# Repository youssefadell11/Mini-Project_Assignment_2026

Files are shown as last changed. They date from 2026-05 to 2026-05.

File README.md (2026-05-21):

# Cooling and Sorting Automated Chocolate Bars Production Line 🍫🤖

## Project Overview
This repository contains the mechanical design, electrical schematics, mathematical models, and simulation files for an automated mechatronic production line. The system is engineered to seamlessly convey, cool, weigh, and sort chocolate bars in a high-throughput food processing environment.

## Key Features
* **Closed-Loop Thermal Management:** Dynamic forced-air cooling modulated by a PID controller responding to real-time non-contact IR temperature feedback ($20^\circ$C target).
* **Adaptive Conveyor Speed:** Variable speed regulation (nominal $0.1 \text{ m/s}$) to ensure sufficient cooling residence time.
* **Automated Sorting Mechanism:** A 3-axis Cartesian robotic arm and pneumatic diversion system for high-speed rejection of out-of-spec products (overheated, under-cooled, or improper weight).
* **Dual-Controller Architecture:** Distributed computing utilizing ESP-based microcontrollers for parallel processing of motor control (PWM) and sensor arrays (HX711 Load Cell, MLX90614 IR).

## Repository Contents
* `/1_CAD`: 3D assembly and part files for the conveyor, rotary feeder, and Cartesian robotic sorter.
<p align="center">
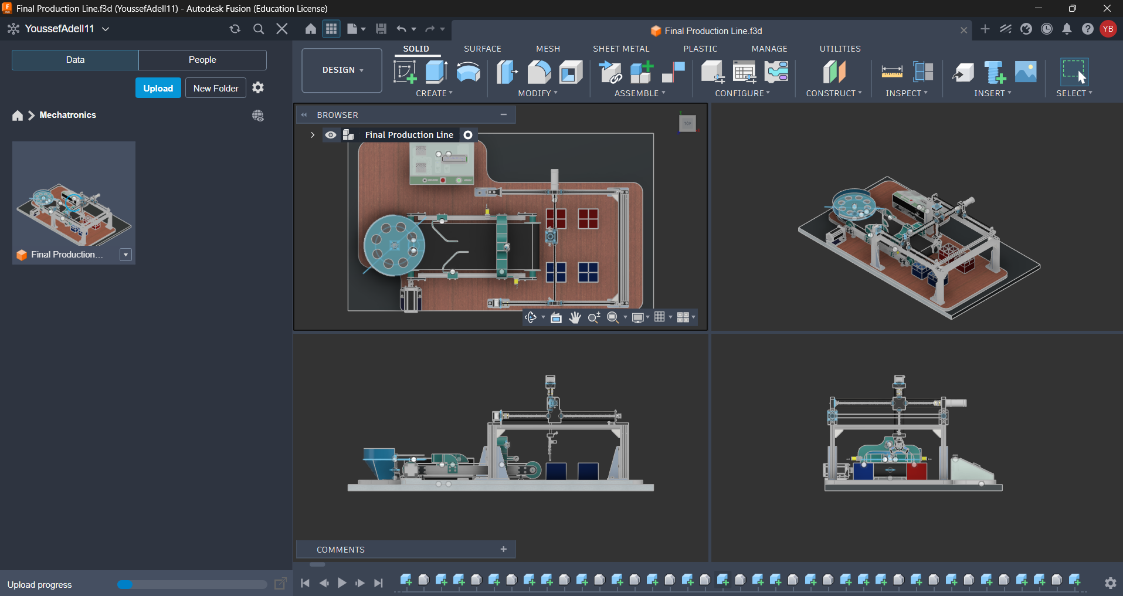
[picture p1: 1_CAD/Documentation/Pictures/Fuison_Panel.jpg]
Fusion Panel
  
</p>

* `/2_Simulation`: MATLAB Simscape physical network models and Simulink block diagrams for the PID control and thermal dynamics.
<p align="center">
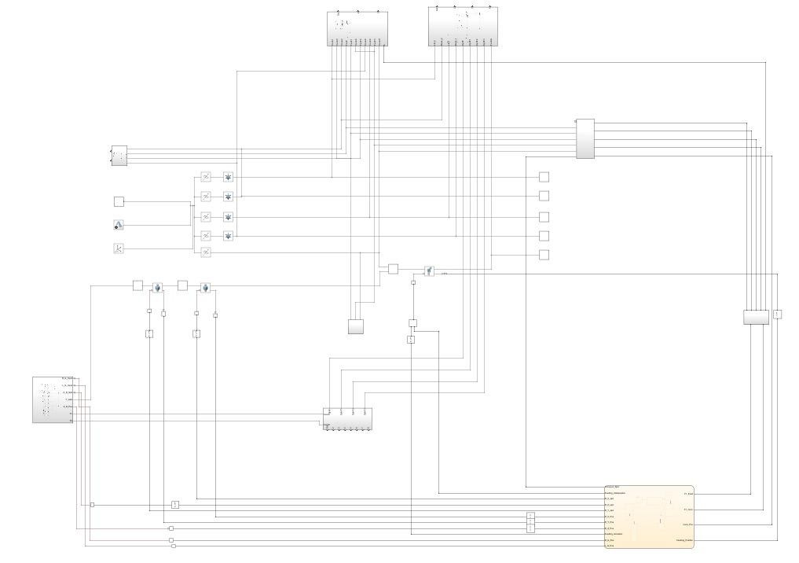
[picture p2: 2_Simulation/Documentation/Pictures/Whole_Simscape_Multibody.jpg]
Simscape Multibody
  
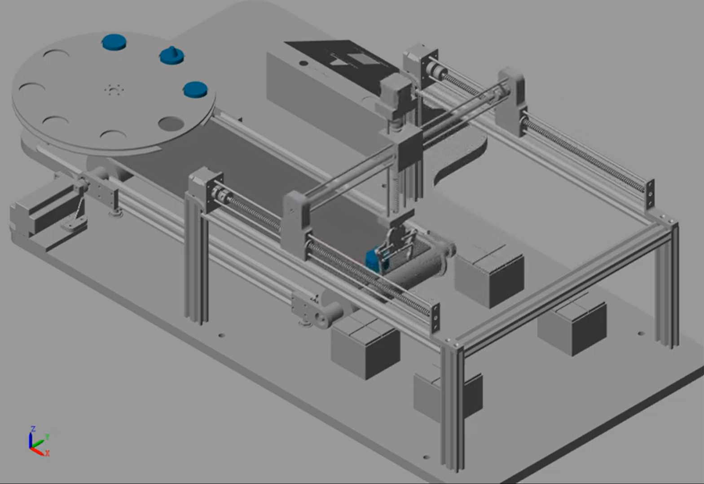
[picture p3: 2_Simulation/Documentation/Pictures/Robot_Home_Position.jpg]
Robot Home Position
  
</p>

* `/3_Documentation`: The final compiled LaTeX technical report and force analysis derivations.

## Technologies Used
* **Simulation & Control:** MATLAB, Simulink, Simscape
* **Computing:** ESP32/Arduino, C++
* **CAD Design:** Autodesk Fusion 360

## Demonstration & Files

* 🎥 **YouTube Video:** [CAD Design: Automated Cooling and Sorting Chocolate Production Line](https://youtu.be/Yx4FxSzs9Yo)
* 📊 **YouTube Video:** [MATLAB Simulation: Automated Cooling and Sorting Chocolate Production Line](https://youtu.be/9laI-daexsU)
* 🛠️ **Interactive Model:** [View the 3D CAD Assembly on Autodesk Fusion 360](https://a360.co/4fo8kH5)

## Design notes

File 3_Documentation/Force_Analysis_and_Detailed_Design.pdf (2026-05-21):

## 1 Actuator Sizing

### 1.1 Actuator Sizing for Gripper

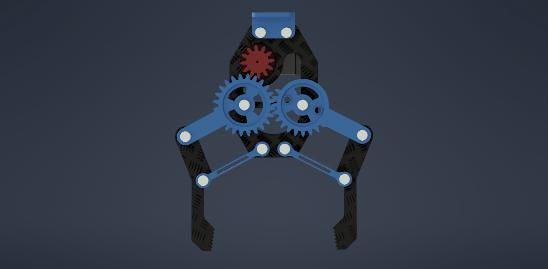
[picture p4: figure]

Figure 1: Gripper Mechanism

1- Normal Force Move Up:

Fup ≥

m(g + a)
2u

Fup =

m(g + a)
2u

× S.f

The required force (F) is calculated as:

Fup =

0.04 × (9.8 + .4)
2 × 0.4

× 2

Fup = 1.02 N

Calculation of Torque:
T = F × d

Tup = 1.02 × .1 = 0.102 N.m

2- Force Move Sideways:

Freq =

p
fx² + fy²

Freq =

p
(ma)

2 + (mg)

2

The required force (F) is calculated as:

Fside =

p
(ma)

2 + (mg)

2
2u

× S.f

Fside =

p
(.04 × .4)² + (9.8 × .04)² 2 × .4

× 2

Fside = .98 N

Calculation of Torque:
T = F × d

Tside = .98 × .1 = 0.098 N.m

Symbol | Value | Units
us | 0.4
g | 9.8 | m/s²
S.f | 2
m | 0.04 | kg
a | 0.4 | m/s²
d | 0.1 | m

3- Force Move down:

Fdown ≥

m(g − a)
2u

Fdown =

m(g − a)
2u

× S.f

The required force (F) is calculated as:

Fdown =

0.04 × (9.8 − .4)
2 × 0.4

× 2

Fdown = .94 N

Calculation of Torque:
T = F × d

Tdown = .94 × .1 = 0.094 N.m

4- Validation: From analysis, the gripper mechanism requires a peak torque = 0.102 N-m.
The selected MG996R Servo Motor has a maximum torque of 1.1 N-m (in its datasheet).
Since this value is significantly higher than the required peak torque = 0.102 N-m, the motor provides a large safety margin and ensures stable and reliable gripping performance.

### 1.2 Actuator Sizing for Z-Axis

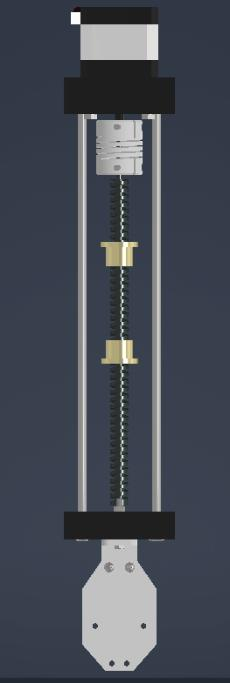
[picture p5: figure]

Figure 2: Z-Axis Mechanism

Symbol | Value Used | Units (SI)
mL | 1.118 | kg
η | 0.40
ρ | 7800 | kg/m³
D | 8 | mm
L | 0.400 | m
P | 0.125 | rev/mm
g | 9.81 | m/s²
tacc | 0.160 | s
tc | 0.500 | s
tdec | 0.160 | s
θacc | 392.70 | rad/s²
Θ′
max | 62.83 | rad/s
Ninertia | 1 | JL,total/Jm
S.f | 1.5

1- Inertia Calculations
Effective Load Inertia:
| JL = mL
| η[2πp]

2

| JL =
| 1.118
.40[2π × 125]²

JL = 4.5302 × 10⁻⁶
| | kg.m²

Lead Screw Inertia:
| Jscrew = π
| 2

ρLr⁴

Jscrew =

π
2

× 7800 × .4 × .004⁴

Jscrew = 1.2546 × 10⁻⁶
kg.m²

Total Load Inertia:
JLt = Jscrew + JL = 5.7848 × 10⁻⁶ kg.m²

Equivalent Inertia:
JLt = Jm

Jeq = JLt + Jm = 2JLt
Jeq = 1.1570 × 10⁻⁵
kg.m²

2- Load Torque Calculation Load Force:
fL = ML × g

fL = 1.118 × 9.8 = 10.9694 N

Load Torque:

TL =

FL
2πp × η

TL = 0.0349 N.m

3- Motion Profile
Assume a motion profile where: Θ′

max = 62.83 rad.s⁻¹
, tacc = 0.160 s, tc = 0.500 s, tdec = 0.160 s, tdwell = 0.

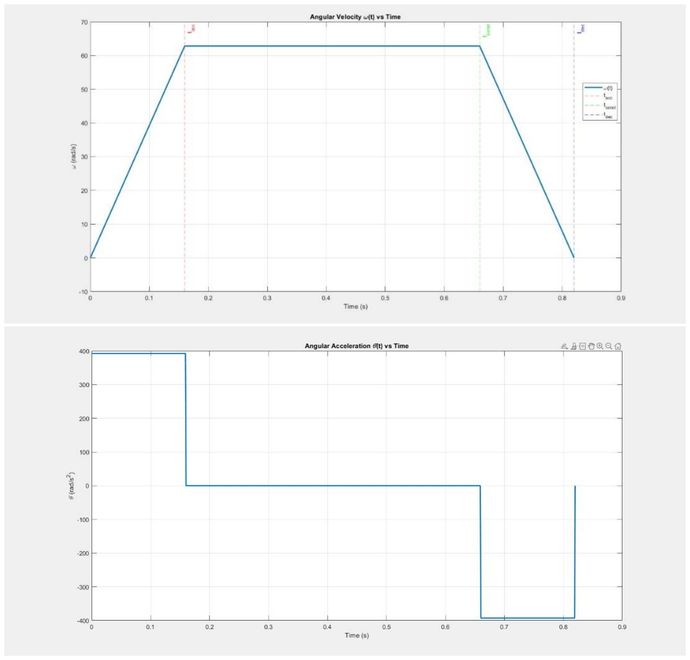
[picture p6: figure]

Figure 3: Angular Velocity and Acceleration vs Time

Now calculate the angular acceleration:

θacc = 392.70 rad.s⁻²

θconst = 0
θdec = −392.70 rad.s⁻²

4- Peak and RMS Torque Calculations Acceleration Torque:
Tm = Jeq

¨θ + TL

Tmacc = (1.1570 × 10⁻⁵ × 392.7) + 0.0349

Tmacc = 0.0395 N.m

Tpeak = Tmacc × S.f = 0.05925 N.m

Constant Velocity Torque:
Tmc = TL = 0.0349 N.m

Deceleration Torque:
Tmdec = (1.1570 × 10⁻⁵ × −392.7) + 0.0349

Tmdec = 0.0304 N.m

Peak Torque (RMS):

Trms =

s
Tmacc

2 × tacc + Tmc

2 × tc + Tmdec

2 × tdec

tacc + tc + tdec

× S.f

Trms =

r
0.0395² × 0.16 + 0.0349² × 0.5 + 0.0304² × 0.16 .820

× 1.5

Trms = 0.05265 N.m

5- Validation Based on the analysis, the Z-axis linear motion requires a peak torque = 0.05925 N-m and an RMS torque = 0.05265 N-m. The selected NEMA 17 Stepper Motor has a maximum torque = 0.59 N-m. Since this value is much higher, the motor provides a large safety margin.

### 1.3 Actuator Sizing for Y-Axis

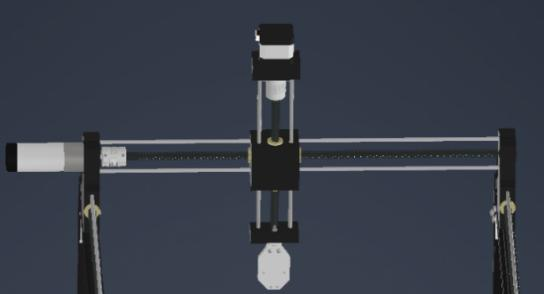
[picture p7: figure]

Figure 4: Y-Axis Mechanism

Symbol | Value | Units
η | 0.40
P | 0.125 | rev/mm
D | 8.0 | mm
mL | 1.320 | kg
Lscrew | 600 | mm
S.f | 1.5
g | 9.81 | m/s²
tacc | 0.1600 | s
tc | 4.8400 | s
tdec | 0.1600 | s
Θ′
max | 62.8319 | rad/s
θacc | 392.6991 | rad/s²
Ninertia | 1.0

1- Inertia Calculations
Effective Load Inertia:
JL =

1.320
.40[2π × 125]²

= 5.349 × 10⁻⁶
kg.m²

Lead Screw Inertia:

Jscrew =

π
2

× 7800 × .6 × .004⁴ = 1.882 × 10⁻⁶ kg.m²

Total Load Inertia:
JLt = Jscrew + JL = 7.2304 × 10⁻⁶ kg.m²

Equivalent Inertia:
Jeq = 2JLt = 1.4461 × 10⁻⁵ kg.m²

2- Load Torque Calculation Load Force:
fL = 1.320 × 9.8 = 12.936 N

Load Torque:

TL =

FL
2πp × η

= 0.0412 N.m

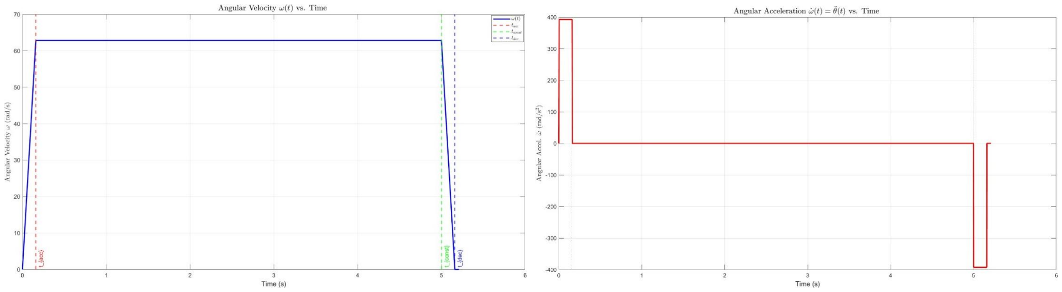
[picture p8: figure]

Figure 5: Angular Velocity and Acceleration vs Time (Y-Axis)

4- Peak and RMS Torque Calculations

Tmacc = (1.4461 × 10⁻⁵ × 392.7) + 0.0412 = 0.0469 N.m

Tpeak = Tmacc × S.f = .0703 N.m

Deceleration Torque:

Tmdec = (1.4461 × 10⁻⁵ × −392.7) + 0.0412 = 0.0355 N.m

Trms =

r
0.0469² × 0.16 + 0.0412² × 4.8400 + 0.0355² × 0.16
5.16

× 1.5 = 0.0618 N.m

5- Validation Based on the analysis, the Y-axis linear motion requires a peak torque = 0.0703 N-m and an RMS torque = 0.0618 N-m. The selected 25GA370 DC Gear Motor with Magnetic Encoder has a stall torque = 0.765 N-m. Since this value is much higher, the motor provides a large safety margin.

### 1.4 Actuator Sizing for X-Axis

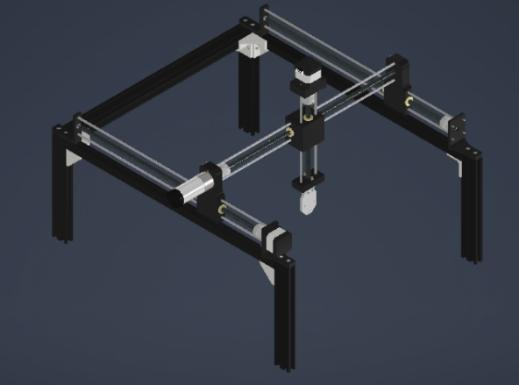
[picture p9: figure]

Figure 6: X-Axis Mechanism

Symbol | Value | Units
mL | 2.200 | kg
Lscrew | 500 | mm
tacc | 0.1600 | s
tc | 5.465 | s

Effective Load Inertia:
JL =

2.200
.40[2π × 125]²

= 8.916 × 10⁻⁶
kg.m²

Total Load Inertia:
JLt = Jscrew + JL = 1.0484 × 10⁻⁵ kg.m²

Equivalent Inertia:
Jeq = 2JLt = 2.0969 × 10⁻⁵
| | kg.m²

Load Force:
fL = 2.2 × 9.8 = 21.56 N

TL =

FL
2πp × η

= 0.0686 N.m

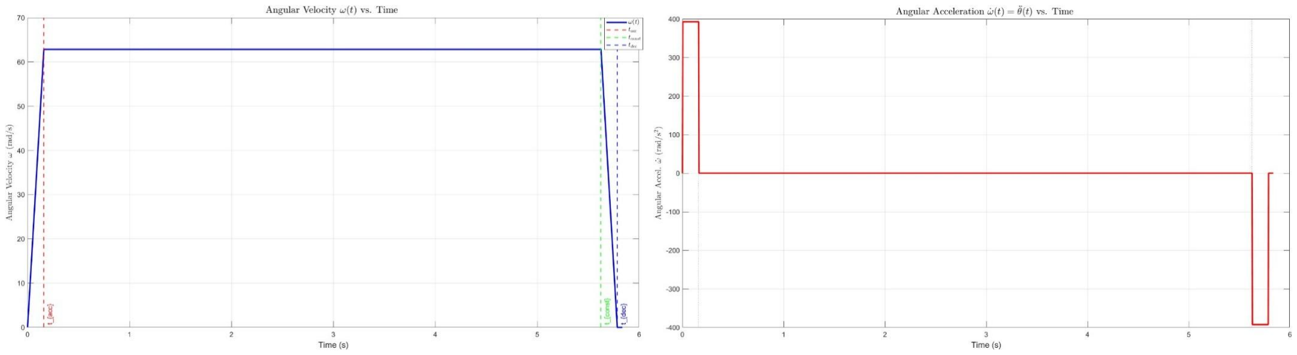
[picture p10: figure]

Figure 7: Angular Velocity and Acceleration vs Time (X-Axis)

Tmacc = (2.0969 × 10⁻⁵ × 392.7) + 0.0686 = 0.0769 N.m

Tpeak = Tmacc × S.f = .115 N.m

Trms =

r
0.0769² × 0.16 + 0.0686² × 5.465 + 0.0604² × 0.16 5.785

× 1.5 = 0.103 N.m

5- Validation
Based on the analysis, the X-axis linear slide requires a peak torque = 0.115 N·m and an
RMS torque = 0.103 N·m. The selected NEMA 17 Stepper Motor (Model: 17HS19-2004S1) has a maximum torque = 0.59 N·m (according to its datasheet). Since this value is much higher than the required peak torque = 0.115 N·m, the motor provides a large safety margin, ensuring reliable performance under acceleration and varying load conditions.

### 1.5 Actuator sizing for conveyor belt

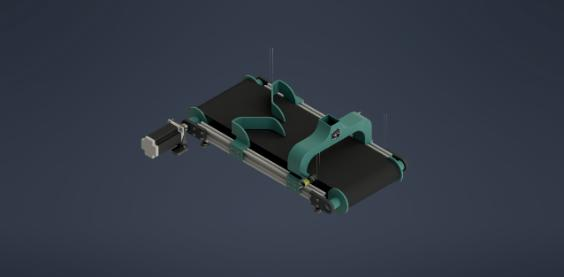
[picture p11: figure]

Figure 8: Conveyor Belt Mechanism

Symbol | Value | Unit
ML | 0.04 | kg
MC | 0.20 | kg
Mtotal | 0.24 | kg
r | 0.02 | m
L | 0.13 | m
ρ | 1240 | kg/m³
η | 0.45
S.f | 1.5
Nrollers | 2
tacc | 0.70 | s

Effective Load Inertia:

JL =

r

2 × mL
η

=

.04 × (.02)²
| .45

= 3.556 × 10⁻⁵
kg.m²

Rollers Inertia:

Jrollers =

π
2

ρLr⁴ × 2 = 8.103 × 10⁻⁵
kg.m²

Equivalent Inertia:
Jeq = 2JLt = 7.87 × 10⁻⁴
| | kg.m²

Load Force and Torque:
fL = ML × g = .24 × 9.8 = 2.352 N

TL =

r × fL
η

= 0.105 N.m

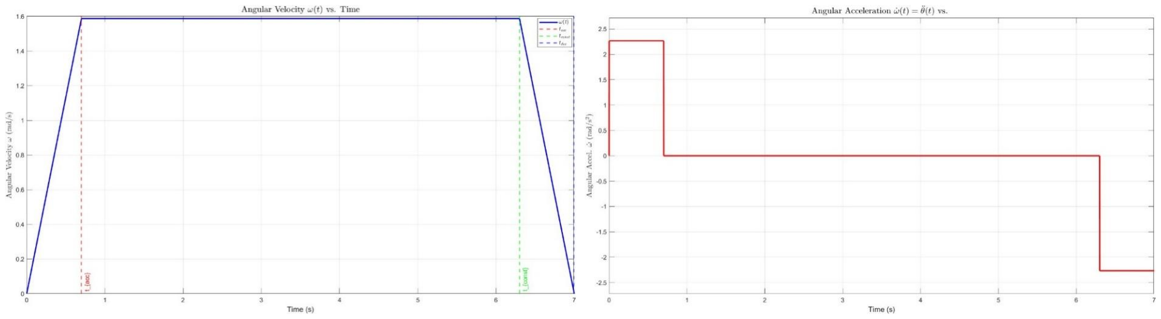
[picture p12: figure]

Figure 9: Velocity and Acceleration for Conveyor

Acceleration Torque:

Tmacc = (7.87 × 10⁻⁴ × 2.27) + 0.105 = 0.1064 N.m

Tpeak = Tmacc × S.f = .16 N.m

Trms =

r
0.1064² × 0.7 + 0.105² × 5.6 + 0.103² × 0.7 7

× 1.5 = 0.157 N.m

5- Validation
Based on the analysis, the conveyor belt drive requires a peak torque = 0.16 N·m and an
RMS torque = 0.157 N·m. The selected NEMA 17 Stepper Motor (Model: 17HS19-2004S1) has a maximum torque = 0.59 N·m, (as specified in its datasheet). Since this value is much higher than the required peak torque = 0.16 N·m, the motor provides a large safety margin, ensuring reliable performance during startup and under variable load conditions throughout continuous operation.

### 1.6 Actuator sizing for Feeder disk

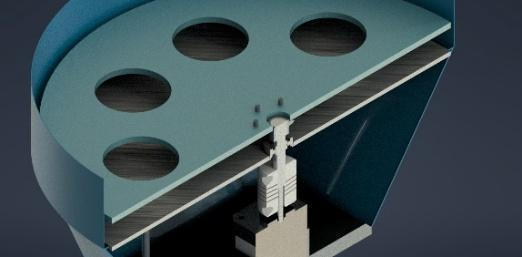
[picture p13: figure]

Figure 10: Feeder Disk

Symbol | Value | Unit
Mdisk | 0.15 | kg
Mproducts | 0.16 | kg
Mtotal | 0.31 | kg
rdisk | 0.02 | m
d | 0.1 | m
ICG | 4.019 | kg-mm²

Disk Inertia:

Jdisk =

1
2

Mdisk × rdisk

2 = .001172 kg.m²

Product Inertia:

Jproducts = ICG + Mproducts × d

2 = 4.019 × 10⁻⁶ + .16 × .1 2 = .001604 kg.m²

Equivalent Inertia:
Jeq = 2JLt = .005552 kg.m²

Load Torque:
fL = (Mdisk + Mproducts) × g = .31 × 9.8 = 3.04 N

TL = fL × d = 0.304 N.m

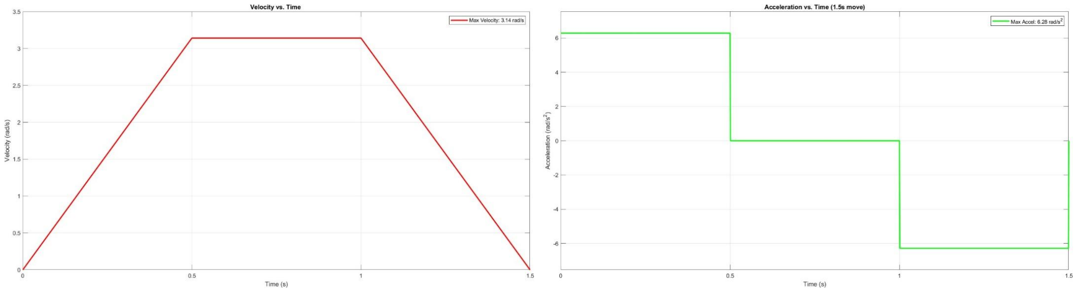
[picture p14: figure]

Figure 11: Feeder Disk Kinematics

Tmacc = (.005552 × 6.283) + 0.304 = 0.339 N.m

Tpeak = Tmacc × S.f = .51 N.m

Trms =

r
0.339² × 0.5 + 0.304² × 0.5 + 0.27² × 0.5 1.5

× 1.5 = 0.46 N.m

5- Validation
Based on the analysis, the feeding mechanism requires a peak torque = 0.51 N·m and an
RMS torque = 0.46 N·m. The selected NEMA 17 Stepper Motor (Model: 17HS19-2004S1) has a maximum torque = 0.59 N·m, (as stated in its datasheet). Since this value is higher than the required peak torque = 0.51 N·m, the motor provides a sufficient safety margin, ensuring reliable and consistent performance for the feeding mechanism’s operation

## 2 Proper Material Selection and Manufacturing Processes

Part Name | Category | Material | Manufacturing Type | Quantity
Feeder Disk | Feeder | PLA | 3D Printing | 1
Feeder Complementary Part | Feeder | PLA | 3D Printing | 1
Feeder Stepper Motor | Feeder | NEMA 17 | Purchased | 1
Conveyor Belt | Conveyor | Rubber | Purchased | 1
Conveyor Complementary Parts | Conveyor | PLA | 3D Printing | 3
Conveyor Stepper Motor | Conveyor | NEMA 23 | Purchased | 1
Conveyor Frame/Rods | Conveyor | Aluminium | Purchased | 2
Conveyor Rollers | Conveyor | PLA | 3D Printing | 2
X-axis Ball Screw | Robotic Arm | Carbon Steel | Purchased | 1
Y-axis Ball Screw | Robotic Arm | Carbon Steel | Purchased | 1
Z-axis Ball Screw | Robotic Arm | Carbon Steel | Purchased | 1
Linear Rail Shafts | Robotic Arm | Stainless Steel | Purchased | 6
Robot Gripper | Robotic Arm | Aluminium Alloy | Purchased | 1
Gripper Servo Motor | Robotic Arm | Servo | Purchased | 1
X-axis Stepper Motor | Robotic Arm | NEMA 17 | Purchased | 1
Y-axis Stepper Motor | Robotic Arm | DC Encoder | Purchased | 1
Z-axis Stepper Motor | Robotic Arm | NEMA 17 | Purchased | 1
Wooden Base | Structural | Plywood | Carpentry | 1
Motor Holders | Mechanical | Aluminium | Purchased | 5
Product Lids (PLA) | Products | PLA | 3D Printing | 8
Product Bases (PLA) | Products | PLA | 3D Printing | 8
Control Box | Electrical | PLA | 3D Printing | 1

## 3 Stress analysis

### 3.1 Stress analysis Z-Axis

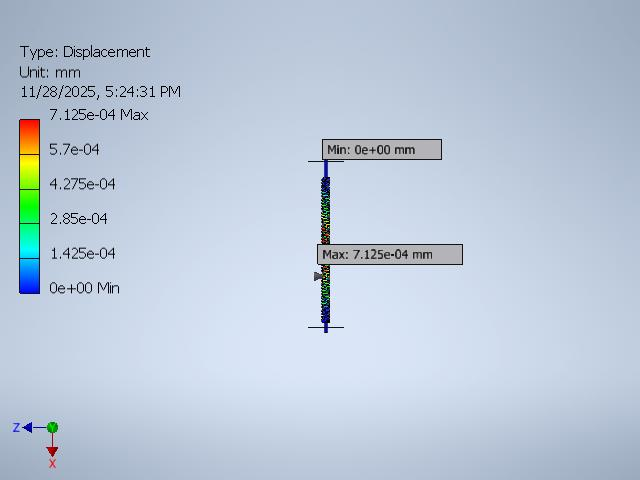
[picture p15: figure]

Figure 12: Stress analysis Z-Axis

Name | Minimum | Maximum
Von Mises Stress | 0.0000237504 MPa | 3.65433 MPa
1st Principal Stress | -0.0990244 MPa | 2.52632 MPa
Displacement | 0 mm | 0.000712513 mm
Safety Factor | 15 ul | 15 ul

### 3.2 Stress analysis Y-Axis

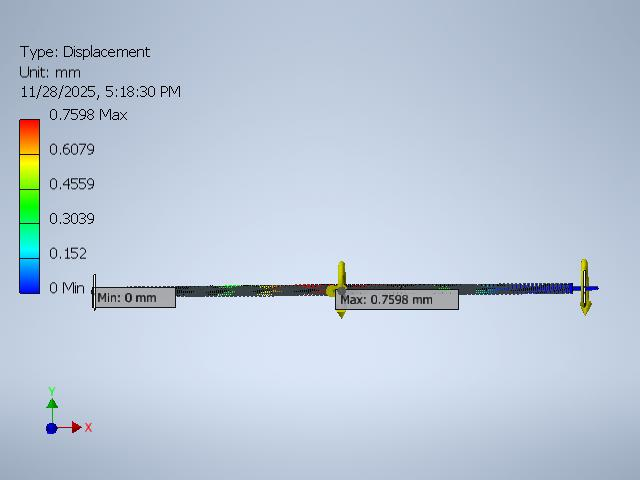
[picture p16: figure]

Figure 13: Stress analysis Y-Axis

Name | Minimum | Maximum
Von Mises Stress | 0.00000675196 MPa | 98.5061 MPa
Displacement | 0 mm | 0.75984 mm
Safety Factor | 7.69495 ul | 15 ul

### 3.3 Stress analysis for X-Axis

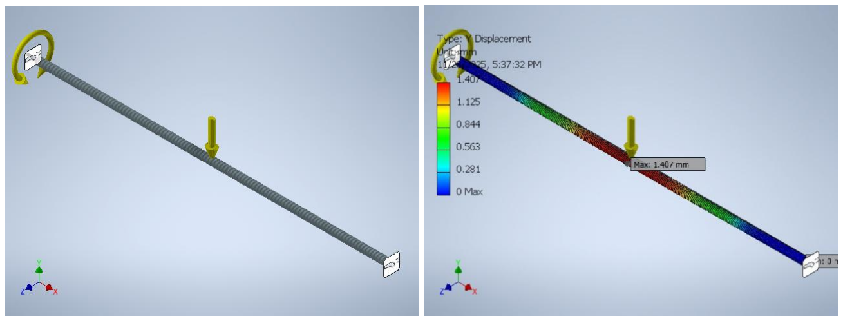
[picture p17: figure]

Figure 14: Boundary condition and Stress analysis for X-Axis

### 3.4 Stress analysis for conveyor belt

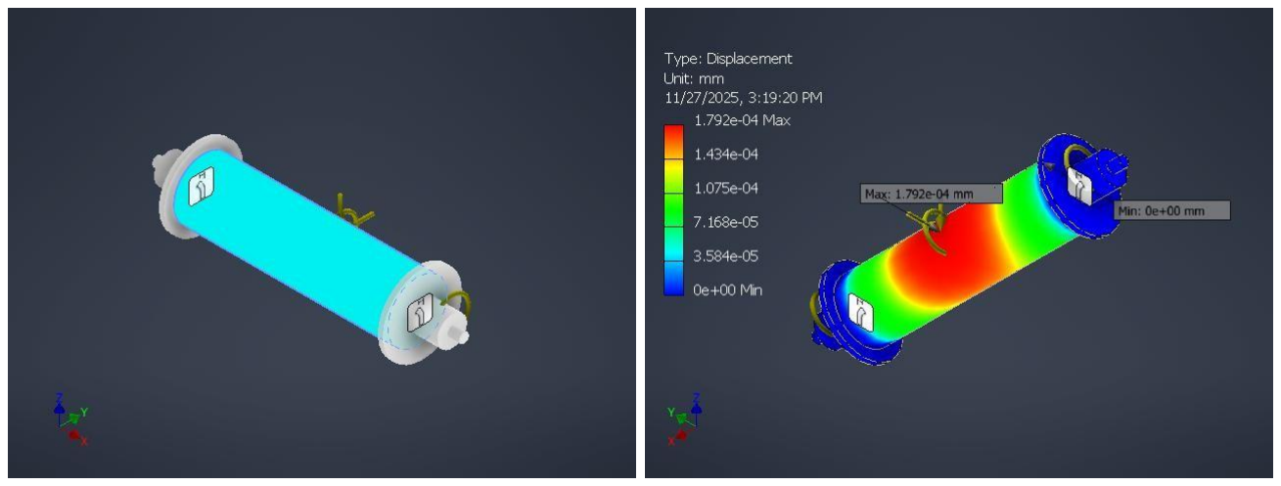
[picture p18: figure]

Figure 15: Boundary condition and Stress analysis for Conveyor Belt

Name | Minimum | Maximum
Von Mises Stress | 0.000000154642 MPa | 0.00790979 MPa
Displacement | 0 mm | 0.000179212 mm
Safety Factor | 15 ul | 15 ul

### 3.5 Stress analysis for Feeder disk

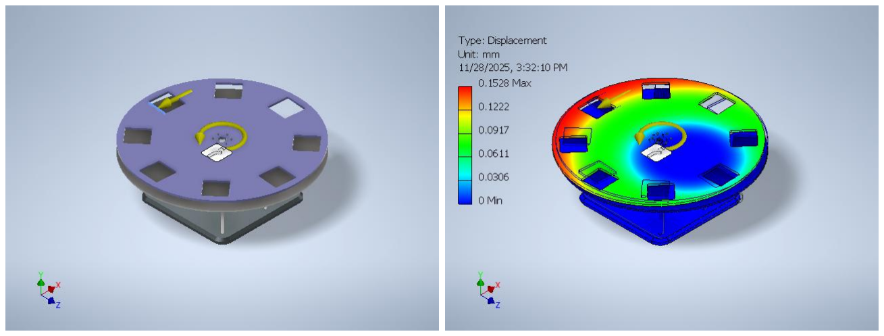
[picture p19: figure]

Figure 16: Boundary condition and Stress analysis for Feeder Disk

### 3.6 Stress analysis for Upper bracket

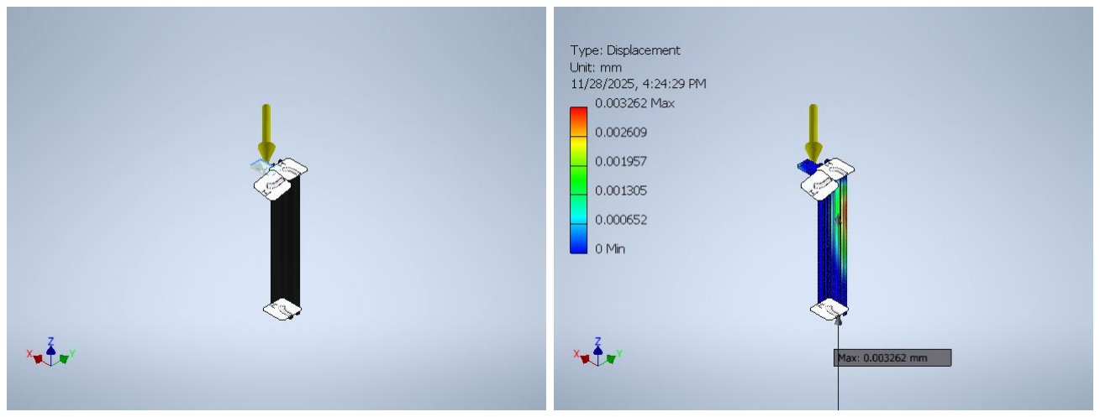
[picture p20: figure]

Figure 17: Boundary condition and Stress analysis for Upper Bracket

### 3.7 Stress analysis for Lower bracket

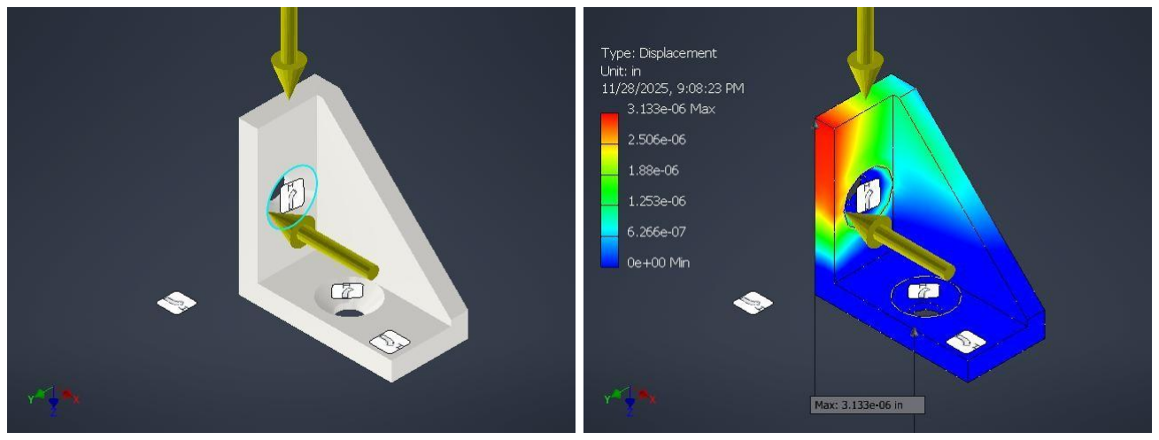
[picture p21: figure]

Figure 18: Boundary condition and Stress analysis for Lower bracket

Name | Minimum | Maximum
Von Mises Stress | 0.00000000255795 ksi | 0.92337 ksi
Displacement | 0 in | 0.00000318725 in
Safety Factor | 15 ul | 15 ul

### 3.8 Stress analysis for screw

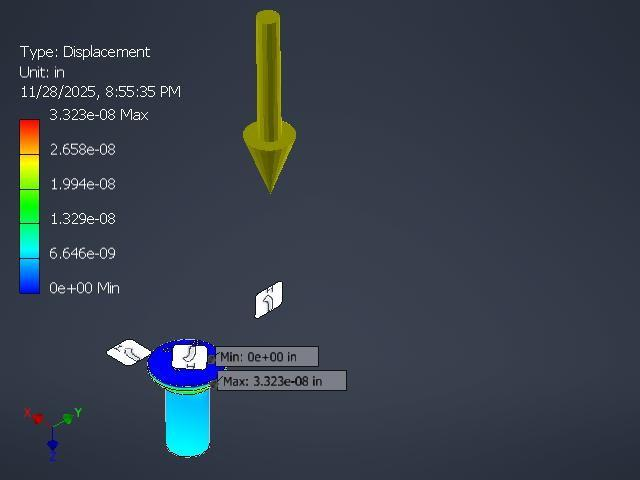
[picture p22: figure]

Figure 19: Stress analysis for screw

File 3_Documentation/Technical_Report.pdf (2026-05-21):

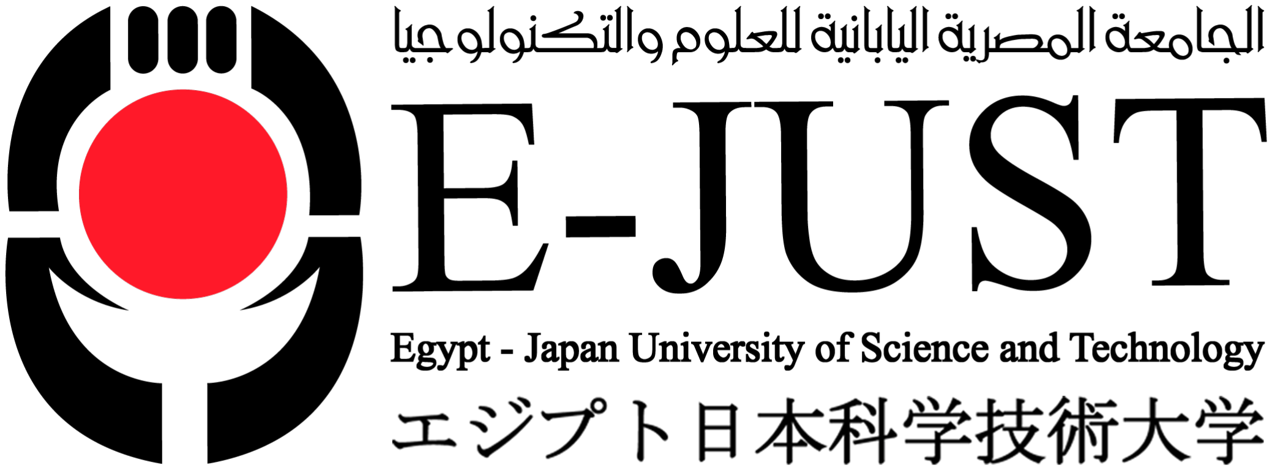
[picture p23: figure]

# MTE 421: Mechatronics Systems Design

# Course Project: Cooling and Sorting Automated Chocolate Bars Production Line

# Spring 2026

### Student Name: Youssef Adel Wahba Boutros Student ID: 120220059

## Contents

1 Introduction and Proposed Solution | 3
2 Component Selection and Justification | 3
3 Force Analysis and Detailed Design | 10
4 System Schematic and Simscape Representation | 11
5 Mathematical Modelling and Control Simulation | 12
6 Fault Detection Procedures | 13
7 Feasibility, Practicability, and Prototyping | 14

## 1 Introduction and Proposed Solution

In modern chocolate manufacturing, maintaining strict thermal profiles is critical to preserving product quality, preventing surface blooming, and ensuring structural integrity.

This report details the design, simulation, and analysis of an automated mechatronic production line designed to convey, cool (to a target of 20◦C), weigh, and sort chocolate bars.

Proposed Innovative Solution:
The proposed system integrates a closed-loop variable-speed conveyor belt with dynamic forced-air cooling. Unlike traditional fixed-speed lines, my system utilizes a primary PID controller to adapt the conveyor’s linear speed (nominally 0.1 m/s) and a secondary PID loop to modulate cooling fan speeds based on real-time surface temperature readings.

A multi-sensor inspection station —combining non-contact infrared (IR) sensors for temperature and dynamic load cells for weight (target 100 g)— acts as the primary feedback node. Defective products (out-of-spec weight, overheated, or under-cooled) are diverted using a high-speed pneumatic sorting mechanism, ensuring zero contamination of the accepted batch.

## 2 Component Selection and Justification

To fulfill the requirements of handling at least 100 chocolate bars continuously, components were selected based on dynamic load requirements, precision, and industrial reliability.

### 2.1 Mechanisms

The mechanical design of the system relies on a precise feeding, conveying, and robotic sorting architecture. The primary mechanisms are detailed below:

- Rotary Feeder Mechanism: A stepper motor uses a central shaft and bearings to rotate a high product disk. The disk features specific pockets where the chocolate bars sit, ensuring each product is perfectly aligned and stopped precisely over the drop-off point to enter the line one by one.

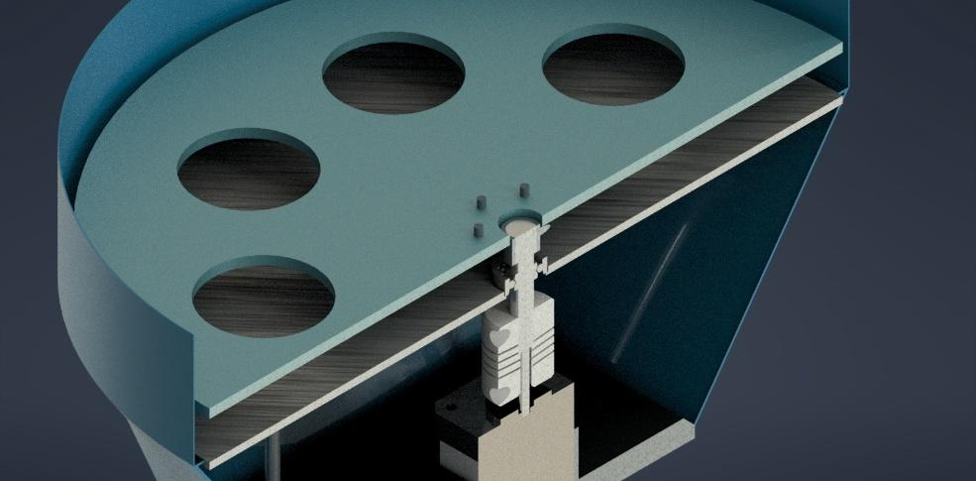
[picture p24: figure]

Figure 1: Feeding Motor and Shaft

- Conveyor Belt: The conveyor moves the products from the feeding mechanism through the cooling zone to the Cartesian robotic sorter.
A stepper motor, connected to the drive roller using a flexible coupler, precisely controls the speed of the belt to allow for adequate cooling time.

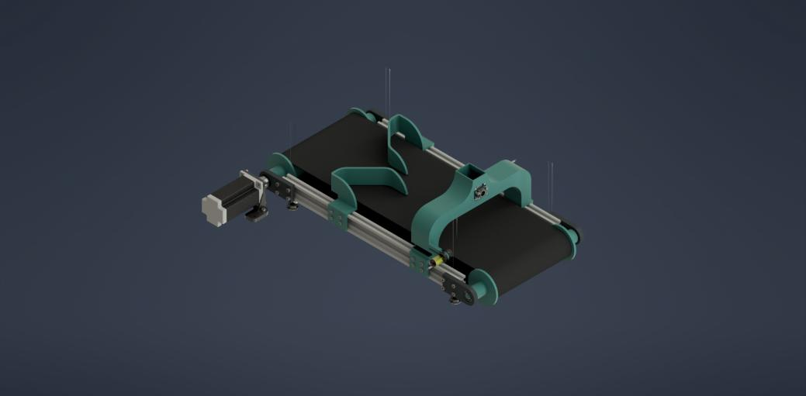
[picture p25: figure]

Figure 2: Conveyor Belt

- Inspection Setup:

– Temperature Sensor: Mounted directly above the conveyor belt.
It reads the surface temperature of the chocolate bar as it passes beneath the opening to ensure it has reached the target 20◦C.

– Shape/Weight Sensor: Mounted at a fixed height above the belt, this sensor sends out a light beam to measure returning light, detecting variations in product height and dimensions to ensure structural integrity.

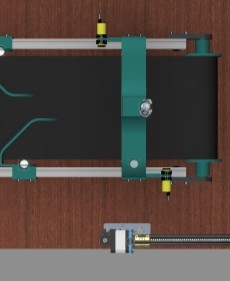
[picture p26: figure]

Figure 3: Inspection Setup

- Cartesian Robotic Arm:
A 3-axis gantry system performs the final sorting operations.

– X-Axis: Constructed from rigid aluminum extrusions with smooth rods acting as guides for stable linear motion. A motor-driven lead screw pushes the carriage, while timing belts and pulleys are utilized for rapid power transmission. Limit switches are installed at the physical ends of the track to prevent over-travel.

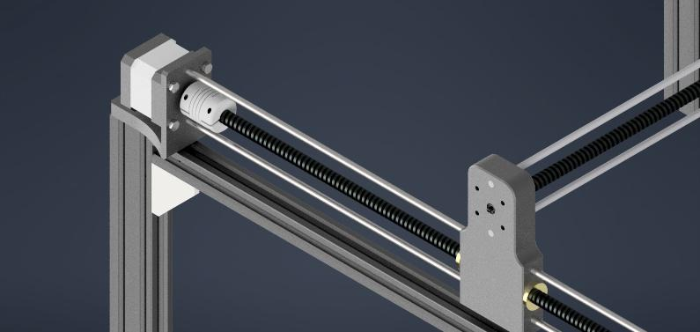
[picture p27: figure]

Figure 4: X-Axis: Lead Screw and Motor

– Y-Axis: Powered by a DC motor equipped with a linear encoder. The encoder provides feedback to ensure the carriage moves forward and backward and stops exactly at the required coordinates. The carriage converts the spinning of the lead screw into straight motion while supporting the entire Z-axis assembly. Limit switches secure the axis boundaries.


Figure 5: Y-Axis: DC Motor with Encoder

– Z-Axis: A stepper motor spins a vertical rod, smoothly connected via a flexible coupler to prevent shaking. This motion drives the end effector up and down.


Figure 6: Z-Axis: Stepper Motor

- The Gripper (End Effector): A custom claw designed to handle the chocolate. A servo motor turns a drive gear, which synchronizes driven gears and linkages to convert the spin into a straight opening/closing motion for the fingers. The servo constantly checks its position, allowing the robot to accurately control the grip force and width so the chocolate is not crushed.


Figure 7: Servo Motor in Gripper

- Base and Infrastructure: The large X-Y-Z frame is anchored to a solid wooden base using standard base supports for stability.

– Storage Area: Contains specific bins where the gripper places the chocolate bars based on their temperature and shape conditions.
After the cooling stage, a sorting mechanism will classify the products into: ∗ Accepted products:
1- Chocolate bars within the desired weight and cooling condition.
∗ Rejected products:
2- Overheated
3- Insufficiently Cooled Bars
4- Improper Weight


Figure 8: Storage Area

– Control Box: Houses the microcontrollers, motor drivers, power supply, emergency stop switch, and necessary circuitry to run the system.


Figure 9: Control Box

- Final Production Line:


Figure 10: Final Production Line Isometric View

### 2.2 Electronics (Sensors)

- Temperature Sensor: An MLX90614 Non-Contact Infrared (IR) Thermometer. Contact sensors would damage the soft chocolate. The IR sensor provides an accuracy of ±0.5

◦C and rapid response times suitable for moving targets.

- Weight Sensor: A dynamic load cell paired with an HX711 24-bit ADC amplifier. The load cell is integrated into a floating section of the conveyor bed to measure the mass of the moving bar (m ≈ 0.1 kg).

### 2.3 Computing, Control, and Wiring Architecture

The electronic circuit forms the central nervous system of the automated chocolate production line, safely bridging the power supply, microcontrollers,
sensor feedback arrays, and heavy-duty actuators.


Figure 11: Wiring schematic demonstrating the integration of the ESP-based controllers, power distribution, and peripheral mechatronic components.

Control Logic and Processing: An ESP-based microcontroller architecture is utilized as the core computing unit. By utilizing a dual-controller setup, the computing load is distributed efficiently: one controller handles the continuous, high-frequency PID calculations for conveyor speed and dynamic fan cooling, while the other processes sensor data (temperature and weight) and triggers the high-speed pneumatic sorting actuator.

Sensor Integration and Actuator Control:

- Actuator Drivers: The main 24V DC gear motor (conveyor drive) and
the 12V BLDC cooling fans are controlled using dedicated high-power motor drivers (H-bridge modules) receiving PWM signals from the ESP controllers.
MOSFET module is used to actuate the 24V pneumatic solenoid valve for the diversion mechanism.
- Feedback Loop: The system reads real-time analog and digital signals from the MLX90614 (IR Temperature) and the HX711 ADC (Load cell/Weight). Additional photoelectric or IR break-beam sensors are positioned at the belt’s entry and exit to track the physical location of the chocolate bars, ensuring precise timing for the sorting diverter.

Power Distribution and Safety:

- Voltage Regulation: Power is delivered by a main industrial power supply (24V DC). To accommodate components with varying voltage requirements, step-down buck converters are heavily utilized to provide stable, regulated 12V for the cooling fans and 5V/3.3V rails for the ESP controllers, logic sensors, and displays. All components share a common ground to ensure stable signal referencing and reliable operation.
- Safety Mechanisms: A physical Start switch initiates the automated sequence, while a hardware Emergency Stop (E-Stop) button is wired to cut power to the main actuators instantly, ensuring safe system operation during a mechanical jam or fault.
- User Interface: A central LCD screen and supplementary digital indicators provide operators with basic, real-time system status information, including current belt speed, average chocolate temperature, and fault codes.

### 2.4 Motor and Motor Drive

- Main Conveyor Motor: A 24V DC brushed gear motor. DC motors, when paired with high-reduction gearboxes, provide excellent low-speed torque characteristics.
- Motor Drive: An industrial H-Bridge MOSFET driver (e.g., Cytron MD30C) capable of handling continuous currents up to 30A. It accepts high-frequency PWM signals from the computing unit to seamlessly adjust the conveyor speed.
- Cooling Fans: 12V Brushless DC (BLDC) fans driven by standard PWM controllers, allowing the system to modulate airflow (convective heat transfer) based on the temperature error.

## 3 Force Analysis and Detailed Design

To correctly size the main conveyor motor, a dynamic load analysis is required. The system must transport at least 100 chocolate bars simultaneously.
System Parameters:
- Mass of a single chocolate bar: mbar = 0.1 kg
- Total load mass: mload = 100 × 0.1 = 10 kg
- Estimated mass of the belt: mbelt = 5 kg
- Total moving mass: mtotal = 15 kg
- Coefficient of kinetic friction (PU belt on steel bed): µk = 0.3
- Drive roller radius: r = 0.05 m
- Nominal linear velocity: v = 0.1 m/s

Required Force and Torque:
The frictional force Ff opposing the motion is calculated as:
Ff = µk · N = µk · mtotal · g | (1)
Ff = 0.3 · 15 kg · 9.81 m/s² = 44.145 N | (2)

The required torque τ at the drive roller is:

τ = Ff · r = 44.145 N · 0.05 m = 2.207 Nm | (3)

To ensure reliability and account for inertial spikes during startup, a safety factor (SF) of 2 is applied, yielding a design torque of 4.41 Nm.
Motor Speed Requirement:
The angular velocity ω of the roller to achieve 0.1 m/s is:

ω =

v
r

=

0.1
0.05
= 2 rad/s | (4)

Converting to Revolutions Per Minute (RPM):

RPM = ω · 60
2π

=

2 · 60
2π
≈ 19.1 RPM | (5)

Motor Selection: Based on these calculations, a 24V DC Gear Motor with a rated torque of 5.0 Nm and a no-load speed of 30 RPM was selected.

Attached Document: Please refer to the attached file
Force Analysis and Detailed Design.pdf
which contains the detailed Actuator Sizing, Proper Material Selection and Manufacturing Processes, and Stress analysis.

## 4 System Schematic and Simscape Representation

The system architecture relies on two primary closed loops. The primary loop regulates the conveyor speed via a PID controller acting on the DC motor driver. The secondary loop monitors the IR temperature sensor and modulates the BLDC cooling fans.
In MATLAB Simscape, the physical network approach was utilized. The model bridges the electrical domain (DC voltage source, H-bridge), mechanical rotational domain (motor inertia, gearbox), and mechanical translational domain (rack-and-pinion analog to simulate rotational-to-linear conversion of the roller and belt).


Figure 12: Simscape Model block diagram.


Figure 13: Simulation of the GUI App

## 5 Mathematical Modelling and Control Simulation

To optimize the system, a mathematical model of the DC motor and the thermal cooling process was derived using Laplace transforms.

### 5.1 Motor Dynamics Transfer Function

The electrical characteristics of the DC motor are defined by:

V (t) = R · i(t) + L

di(t)
| dt + Ke · ω(t) | (6)

The mechanical characteristics are:

Tm(t) = Kt

- i(t) = J
| dω(t)
| dt + b · ω(t) + TL | (7)

Taking the Laplace transform of both equations (assuming zero initial conditions) and applying block reduction techniques yields the transfer function relating the input voltage V (s) to the angular velocity ω(s):

ω(s)
V (s)
= | Kt
| (Ls + R)(Js + b) + KtKe

(8)

Where:

- R, L: Armature resistance and inductance
- J, b: Rotor inertia and viscous friction
- Kt
, Ke: Motor torque and back-EMF constants

### 5.2 Thermal Dynamics Model

The cooling of the chocolate follows Newton’s Law of Cooling. The rate of temperature change is proportional to the difference between the chocolate temperature Tc and the ambient cooling air Ta:
dTc(t)
dt | = −k · (Tc(t) − Ta) | (9)

Where k is the cooling constant, heavily dependent on the convective heat transfer coefficient h, which we control via the fan’s RPM.

### 5.3 Simulation Results

Using Simulink, a PID controller was tuned using the Ziegler-Nichols method to achieve a critically damped response for the conveyor speed. The simulation confirmed that under a step-load disturbance (simulating a sudden influx of chocolate bars), the control system recovers the 0.1 m/s setpoint within 1.2 seconds with less than 5% overshoot.


Figure 14: [Simulink PID response graph (Velocity vs Time).

## 6 Fault Detection Procedures

In an industrial food processing environment, system downtime results in severe material waste. The following fault detection protocols are integrated into the computing logic:

1. Over-Current Detection (Motor Stall): The motor driver continuously monitors current draw. If a jam occurs on the belt, the current will spike. The microcontroller logic states that if Imotor > Ithreshold for more than 2 seconds, the system triggers an emergency stop (E-STOP) and flags a mechanical jam fault.
2. Sensor Failure Redundancy: If the IR temperature sensor returns a value outside the physical realm of the factory (e.g., < 0

◦C or > 100◦C), the system categorizes this as a sensor wire-break or failure. The line pauses, and an alarm alerts the operator, preventing the processing of unmonitored chocolate.

3. Pneumatic Pressure Loss: A digital pressure switch on the main air line ensures the diversion mechanism has sufficient force. If pressure drops below 4 bar, sorting cannot be guaranteed, and the system halts to prevent defective bars from passing.

## 7 Feasibility, Practicability, and Prototyping

Traditional vs. Automated Comparison:
Traditional manual sorting relies on human operators physically checking random samples for temperature and visually inspecting weight/shape. This method is statistically unreliable, labor-intensive, and poses a high risk of biological contamination.
The proposed mechatronic system demonstrates high practicability by offering 100% inline inspection. Every single bar is weighed and thermally scanned. By utilizing real-time dynamic cooling, energy is conserved; fans only operate at maximum RPM when the thermal load dictates, making the system vastly more energy-efficient than continuously running cooling tunnels.

Prototype Implementation:
To validate the design, a scaled-down functional prototype will be developed. It will utilize an Arduino Mega interfacing with a miniature 12V DC conveyor. An MLX90614 sensor will provide real-time thermal data, which will trigger a 12V PC cooling fan via PWM. A micro-servo will be used to simulate the pneumatic diverter. Testing will confirm the control logic: items deliberately heated above the threshold will be detected, subjected to maximum cooling, and if the target temperature is not met by the end of the belt, seamlessly diverted into the rejection bin. This prototype will confirm the scalability and industrial validity of the simulated Simscape models.

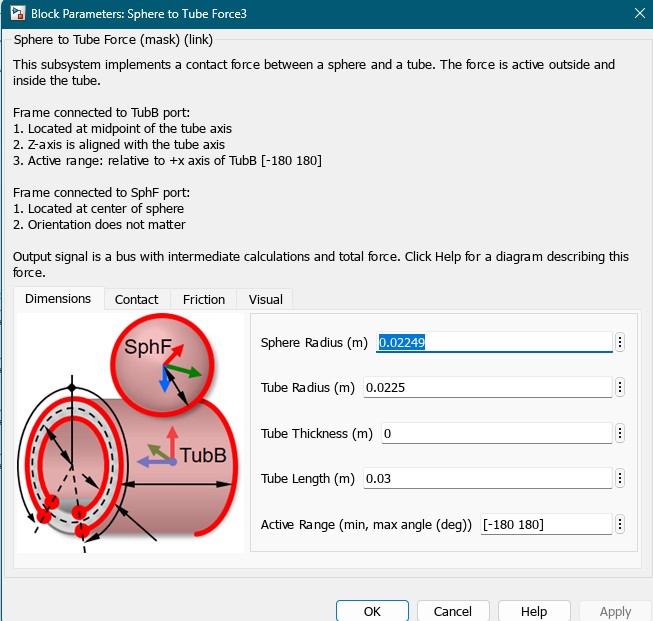
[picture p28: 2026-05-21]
2_Simulation/Documentation/Pictures/Sphere_to_Tube_Force.jpg

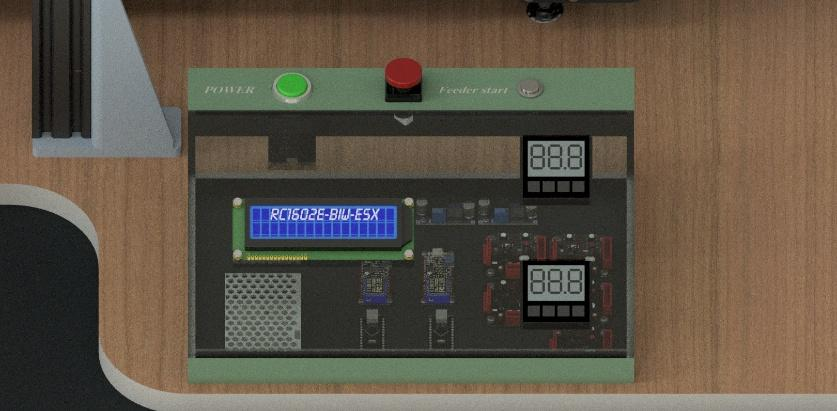
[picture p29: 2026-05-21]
1_CAD/Documentation/Pictures/Control_Box.jpg

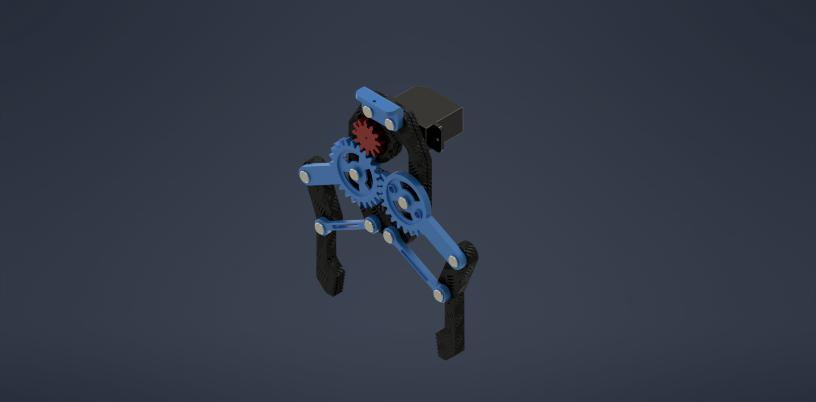
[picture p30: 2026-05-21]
1_CAD/Documentation/Pictures/Servo_motor_in_gripper.jpg

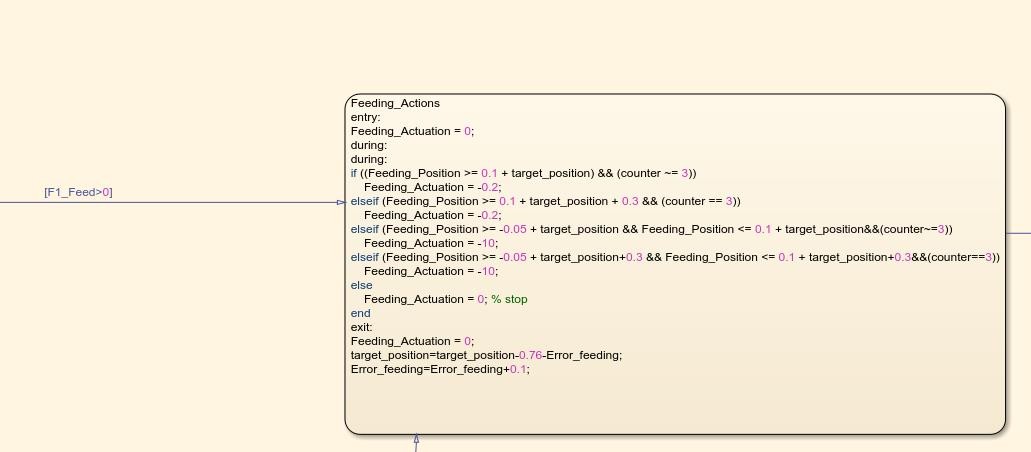
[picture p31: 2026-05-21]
2_Simulation/Documentation/Pictures/Feeding_Actions_State.jpg

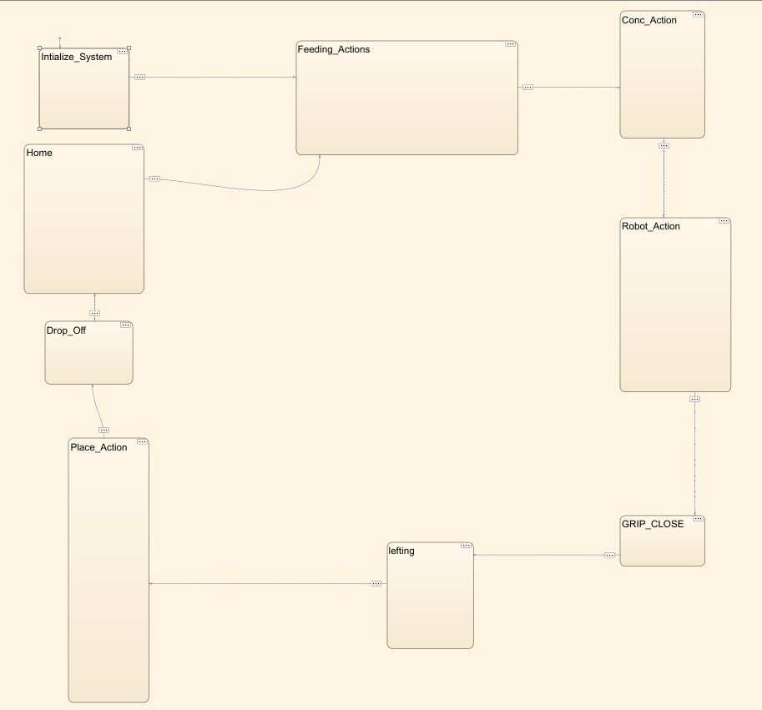
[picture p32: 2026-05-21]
2_Simulation/Documentation/Pictures/Overall_Stateflow.jpg

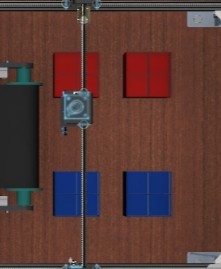
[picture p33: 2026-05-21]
1_CAD/Documentation/Pictures/Storage_Area.jpg

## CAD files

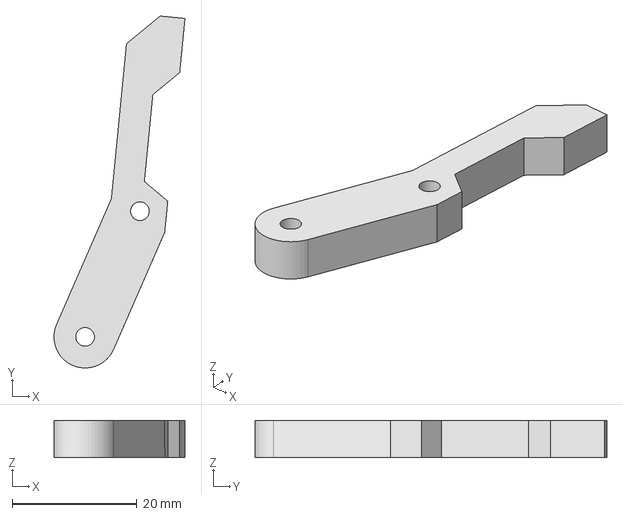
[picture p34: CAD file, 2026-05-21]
2_Simulation/MATLAB_V23/CAD/STEP/Holder_MIR_ipt_4e47ee7f.STEP
21.0 x 56.5 x 6.01 mm

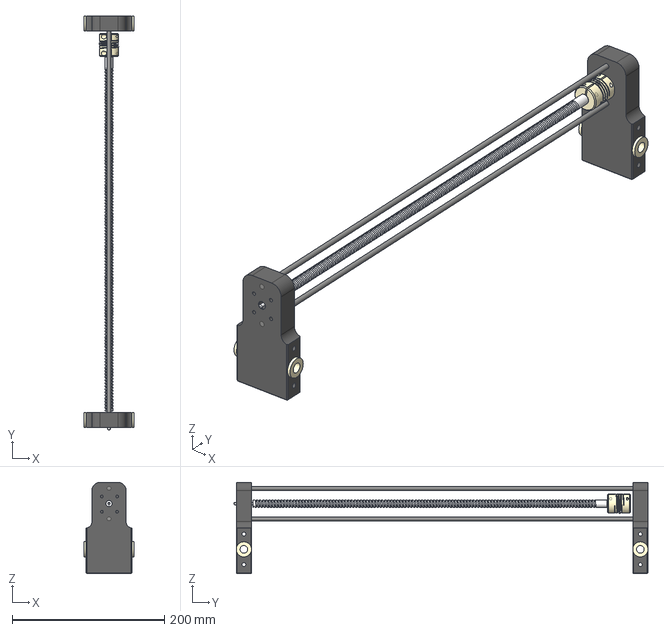
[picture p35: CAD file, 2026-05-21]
2_Simulation/MATLAB_V23/CAD/STEP/X_AXIS_ipt_5f072c36.STEP
66.0 x 543.0 x 120.0 mm

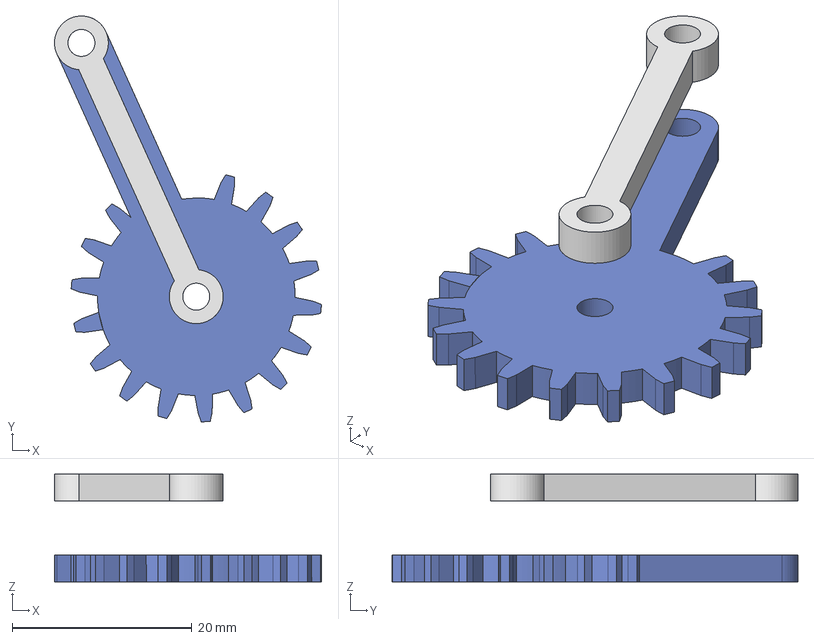
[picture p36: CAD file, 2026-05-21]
2_Simulation/MATLAB_V23/CAD/STEP/Gear_MIR_ipt_9c057dc7.STEP
29.7 x 45.2 x 12.0 mm

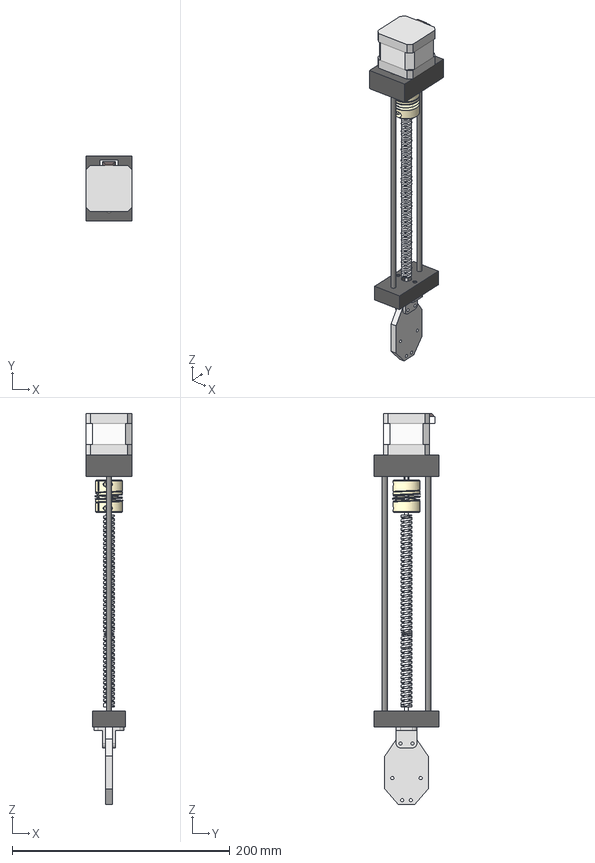
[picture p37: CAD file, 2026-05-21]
2_Simulation/MATLAB_V23/CAD/STEP/Z_AXIS_ipt_52e6de26.STEP
42.3 x 60.0 x 359.0 mm

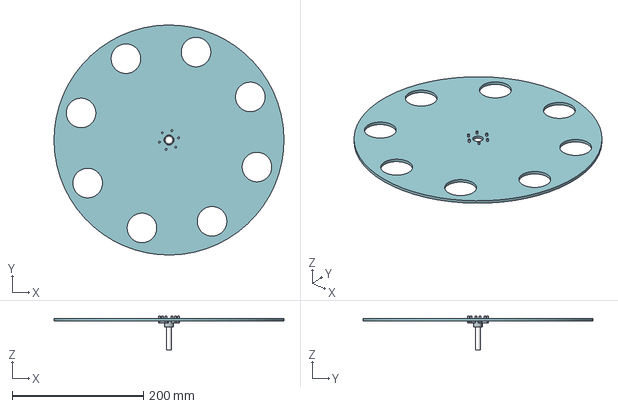
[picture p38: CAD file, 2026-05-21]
2_Simulation/MATLAB_V23/CAD/STEP/FEEDER_1_ipt_81fb8e9d.STEP
350.0 x 350.0 x 51.0 mm

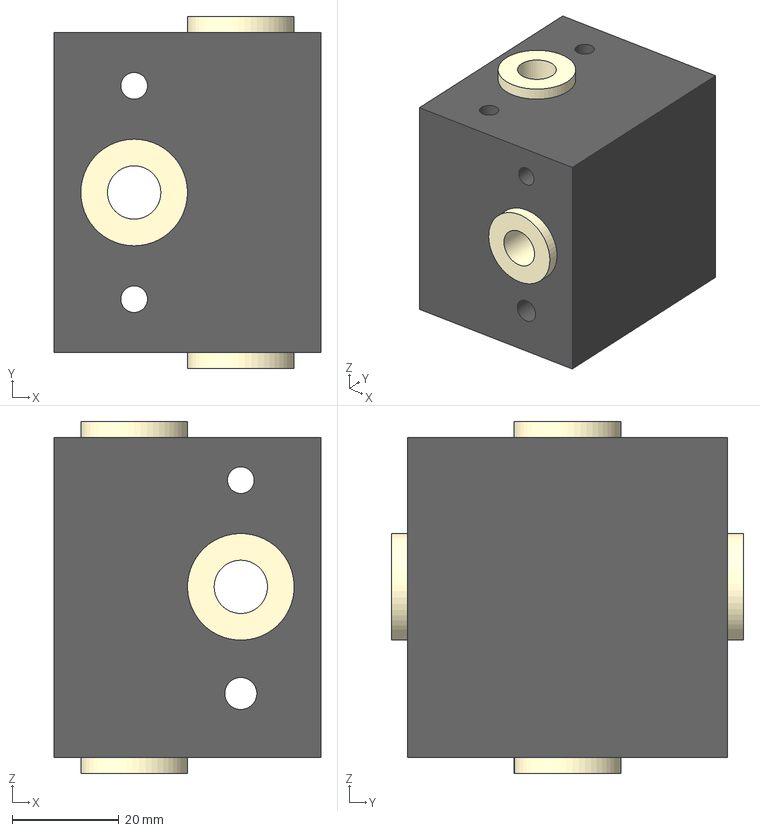
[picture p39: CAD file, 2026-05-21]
2_Simulation/MATLAB_V23/CAD/STEP/Y_AXIS_ipt_f7973972.STEP
50.0 x 66.0 x 66.0 mm

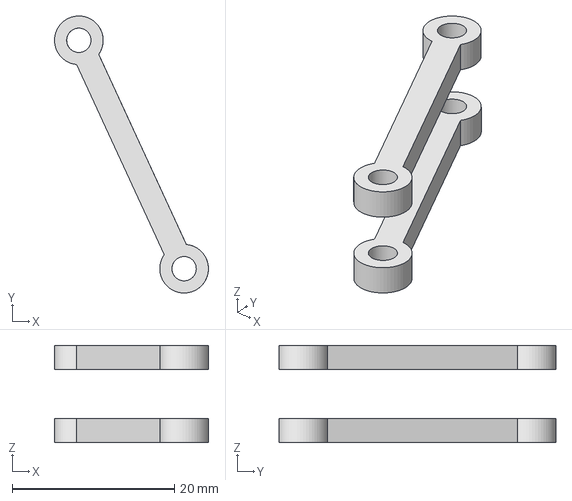
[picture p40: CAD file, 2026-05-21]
2_Simulation/MATLAB_V23/CAD/STEP/Stand_MIR_ipt_bad55de2.STEP
19.0 x 34.1 x 12.0 mm

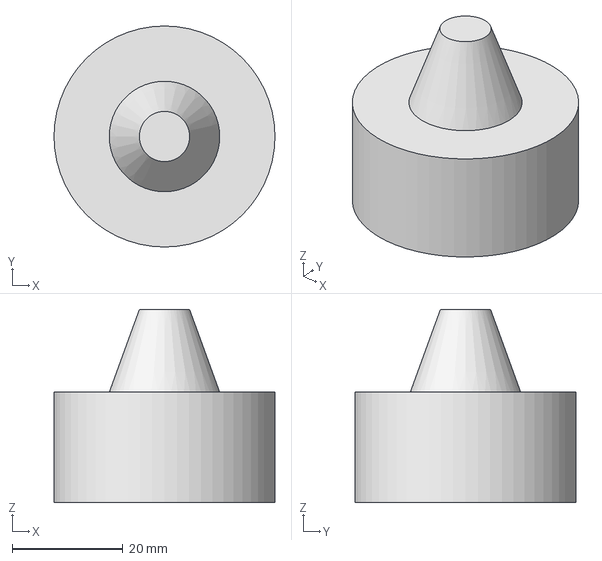
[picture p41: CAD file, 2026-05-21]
2_Simulation/MATLAB_V23/CAD/STEP/base_product_1_ipt_f9f28c9f.STEP
40.0 x 40.0 x 35.0 mm

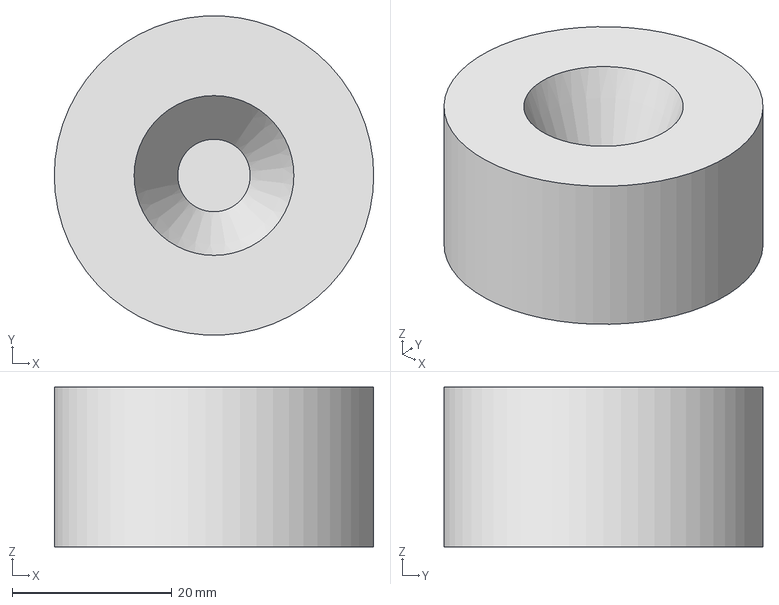
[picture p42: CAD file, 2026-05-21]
2_Simulation/MATLAB_V23/CAD/STEP/LID_Product_1_ipt_3d0ec5a8.STEP
40.0 x 39.9 x 20.0 mm

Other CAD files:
2_Simulation/MATLAB_V23/CAD/STEP/Holder_ipt_575a6bf1.STEP
2_Simulation/MATLAB_V23/CAD/STEP/Gear_ipt_e327140f.STEP
2_Simulation/MATLAB_V23/CAD/STEP/Stand_ipt_5e00ca89.STEP
2_Simulation/MATLAB_V23/CAD/iam/FEEDER_1.ipt
2_Simulation/MATLAB_V23/CAD/iam/Gear.ipt
2_Simulation/MATLAB_V23/CAD/iam/Gear_MIR.ipt
2_Simulation/MATLAB_V23/CAD/iam/Holder.ipt
2_Simulation/MATLAB_V23/CAD/iam/Holder_MIR.ipt
2_Simulation/MATLAB_V23/CAD/iam/LID_Product_1.ipt
2_Simulation/MATLAB_V23/CAD/iam/Stand.ipt
2_Simulation/MATLAB_V23/CAD/iam/Stand_MIR.ipt
2_Simulation/MATLAB_V23/CAD/iam/X_AXIS.ipt
2_Simulation/MATLAB_V23/CAD/iam/Y_AXIS.ipt
2_Simulation/MATLAB_V23/CAD/iam/Z_AXIS.ipt
2_Simulation/MATLAB_V23/CAD/iam/base_product_1.ipt
2_Simulation/MATLAB_V23/CAD/iam/tube.iam
